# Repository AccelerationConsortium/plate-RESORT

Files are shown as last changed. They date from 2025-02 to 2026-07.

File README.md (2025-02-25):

## About the Project
Plate hotels and carousels are **space-efficient storage systems** designed for well plates, making them ideal for **high-throughput automated workflows** in chemistry and biology labs. This project provides **open-source, low-cost instructions** for building modular storage solutions tailored to your lab's needs.

- **Plate Hotel**: The base design accommodates **11 well plates**, but it can be easily customized to be taller or shorter depending on your requirements.
- **Plate Carousel**: Built around a **Raspberry Pi Zero 2 W**, this system features an **automated turntable base** and can hold **6 plate hotels** (totaling **60 well plates**), enabling efficient access and organization.

TODO: add pictures

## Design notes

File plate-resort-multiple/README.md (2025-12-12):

# Plate Resort - Quick Setup Guide

Control laboratory plate handling hardware from your computer.

## Setup Steps

### 1. Get the API Key
SSH into the Pi and get the key:
```bash
ssh your_username@pi_ip_address
cd ~/plate-RESORT/plate-resort-multiple
plate-resort-rest-server
```
Copy the API key shown, then press `Ctrl+C`.

### 2. Install on Your Computer
```bash
git clone https://github.com/AccelerationConsortium/plate-RESORT.git
cd plate-RESORT/plate-resort-multiple
pip install -e .
```

### 3. Set Connection Info
**Windows:**
```cmd
set PLATE_RESORT_API_KEY=your-api-key-here
set PLATE_RESORT_URL=http://sdl3-pi5-plate-resort.tail6a1dd7.ts.net:8000
```

**Mac/Linux:**
```bash
export PLATE_RESORT_API_KEY="your-api-key-here"
export PLATE_RESORT_URL="http://sdl3-pi5-plate-resort.tail6a1dd7.ts.net:8000"
```

### 4. Start the Pi Server
SSH back to Pi:
```bash
plate-resort-rest-server
```
Keep this running.

## Commands

**Check status:**
```bash
plate-resort-rest-client status
```

**Move to hotel:**
```bash
plate-resort-rest-client activate A  # or B, C, D
```

**Go home:**
```bash
plate-resort-rest-client home
```

**Emergency stop:**
```bash
plate-resort-rest-client stop
```

## Troubleshooting

- **Connection refused:** Check Pi server is running and IP address is correct
- **Authentication failed:** Double-check your API key  
- **Motor issues:** SSH to Pi and run `python tests/soft_reset.py`

## For GUI Development

All commands return JSON responses. Use any programming language to build your interface:
- Python (tkinter, PyQt, Streamlit)
- Web (HTML/JavaScript) 
- LabVIEW, MATLAB, etc.

Choose your interface mode based on your needs. Both modes can run on the same Raspberry Pi if needed.

## 2A. Prefect Interface Setup (Recommended)

### 2A.1 Raspberry Pi (Worker Host)
```bash
export PREFECT_API_URL="https://api.prefect.cloud/api/accounts/<account-id>/workspaces/<workspace-id>"
export PREFECT_API_KEY="pnu_XXXXXXXXXXXXXXXX"

python3 -m venv plate-resort-env
source plate-resort-env/bin/activate
pip install -e .
plate-resort-prefect-deploy     # registers deployments
plate-resort-prefect-worker    # starts Prefect worker
```
Optional systemd (adjust path/username):
```bash
sudo cp deployment/plate-resort.service /etc/systemd/system/
sudo systemctl daemon-reload
sudo systemctl enable --now plate-resort.service
```
Environment file (example): `/home/<user>/plate-RESORT/secrets.local.env`
```
PREFECT_API_URL=...
PREFECT_API_KEY=...
PLATE_RESORT_POOL=plate-resort-pool
```

### 2A.2 Client Machine
Two supported approaches:
1. Interactive CLI (`plate-resort-prefect-interactive --remote`)
2. Minimal script (`plate_resort/client/example_prefect_client.py` pattern)

Install only what’s needed:
```bash
python -m venv plate-resort-client
source plate-resort-client/bin/activate
pip install -r client-requirements.txt
```
Export credentials (or source `plate_resort/client/env.sh` after editing IDs):
```bash
source plate_resort/client/env.sh   # edit placeholders first
```
Verify a deployment submission:
```bash
python -c "from plate_resort.interfaces.prefect import orchestrator; print(orchestrator.connect())"
```

## 2B. REST API Interface Setup (Traditional)

### 2B.1 Raspberry Pi (Server Host)
```bash
python3 -m venv plate-resort-env
source plate-resort-env/bin/activate
pip install -e .
plate-resort-keygen                 # generate API key
plate-resort-rest-server           # start FastAPI server
```
The server runs on port 8000 by default. API documentation available at `http://<pi-ip>:8000/docs`

### 2B.2 Client Machine  
```bash
python -m venv plate-resort-client
source plate-resort-client/bin/activate
pip install -e .
export PLATE_RESORT_BASE_URL="http://<pi-ip>:8000"
export PLATE_RESORT_API_KEY="<generated-key>"
plate-resort-rest-client --help    # see available commands
```

Example REST usage:
```bash
# Connect and activate hotel
plate-resort-rest-client connect
plate-resort-rest-client activate A
plate-resort-rest-client position
plate-resort-rest-client disconnect
```

## 3. Client Usage (Prefect Interface)

### 3.1 Interactive CLI
```bash
plate-resort-prefect-interactive --remote
```
Commands:
```
connect | activate <A|B|C|D> | position | stop | disconnect | help | exit
```

### 3.2 Example Script (A -> D)
```bash
python plate_resort/client/example_prefect_client.py
```
That script: activates hotel A, waits, then activates hotel D with state checks.

### 3.3 Direct Orchestrator Calls
```python
from plate_resort.interfaces.prefect import orchestrator
run = orchestrator.activate_hotel("A")
state = orchestrator.wait(run)
print(state.type)
```

## 4. Deployments & Redeploy (Prefect Interface)
Run on Pi whenever code changes:
```bash
plate-resort-prefect-deploy
```
This re-registers function-based flows with Prefect Cloud using the current working tree (Git storage reference if configured).

Pinning / ensuring correct source:

Option A (branch ref):
```bash
export PLATE_RESORT_GIT_REF=copilot/replace-rest-api-with-prefect
plate-resort-prefect-deploy
```
Option B (commit hash, reproducible) – recommended; resolved prior path issues during testing:
```bash
export PLATE_RESORT_GIT_COMMIT=$(git rev-parse HEAD)
plate-resort-prefect-deploy
```
Commit pin (Option B) takes precedence over branch ref and guarantees the worker loads the exact code you just validated.

## 5. Available Flows
All in `plate_resort/interfaces/prefect/flows.py`:
```
connect, disconnect, activate_hotel, move_to_angle,
get_current_position, get_motor_health, go_home,
emergency_stop, set_speed
```
Remote submission uses deployment names of form `flow-name/flow-name` (e.g. `activate-hotel/activate-hotel`).

## 6. Behavior Notes
* Motor connection is re-established per flow if needed and left active afterward (persistent torque).
* Use `disconnect` flow to deliberately release torque/close port.
* `orchestrator.wait()` polls Prefect for a final state.

## 7. Configuration
Search path includes packaged defaults plus optional override directory: `~/plate-resort-config/`.

`defaults.yaml` (excerpt):
```yaml
resort:
  device: "/dev/ttyUSB0"
  hotels: ["A", "B", "C", "D"]
prefect:
  work_pool_name: "plate-resort-pool"  # Overridden by PLATE_RESORT_POOL
```

To override: create `~/plate-resort-config/defaults.yaml` with keys you want to change; unspecified values fall back to packaged defaults.

## 8. Minimal Client Assets
* `client-requirements.txt` – pins `prefect` + `pyyaml` (add `dynamixel-sdk` only if talking directly to hardware from client).
* `plate_resort/client/env.sh` – template for exporting Prefect API variables.
* `plate_resort/client/example_prefect_client.py` – sequential A -> D example.

## 9. Troubleshooting
| Symptom | Likely Cause | Fix |
|---|---|-----|
| Flow run stays SCHEDULED | Worker not running or wrong pool | Start worker; confirm pool name or set PLATE_RESORT_POOL |

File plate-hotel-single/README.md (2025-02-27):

# Plate Hotel Build Guide
This document provides the steps required to assemble the plate hotel. Please review all instructions and notes before starting the build.

## Bill of Materials
### Purchased Parts

| # | McMaster Part # | Part Description | Quantity |
|-----|---|---|---|
| A1  | 92125A234 | M6 FH screw, 10mm L, SS | 22 |
| A2  | 93590A106 | M6 Coupling Nut, 18mm L, SS | 22 |
| A3  | 94639A569 | M6 Spacer, 1/4in L, Nylon | 3 |
| A4  | 92095A224 | M6 PH Screw, 10mm L, SS | 22 |
| A5  | 8961K96 | DIN 3 Rail, 600mm L, S | 1 |
| A6  | 4844N123 | single closed gusset for 25mm rail (with fasteners) | 3 |
| A7  | 92095A128 | M6 PH Screw, 15mm L, SS | 3 |
| A8  | 4633N79 | extrusion, square, 25mm, 2ft L | 1 |
| A9  | 94180A371 | M6 heat set insert | 3 |
| A10 | 3136N534 | cap, 25mm rail | 1 |
| A11 | 91458A115 | threadlocker, Loctite 243 (medium) | N/A |

<sub>Note: I like stainless steel screws, this is not necessary. The lengths are listed in the part description.</sub>
---

### 3D Printed Parts

| # | Filament Qty (g) | Part Name | Part Qty |
|-----|---|---|---|
| B1  | 48.9 | well plate tray | 11 |
| B2  | 50 | plate hotel base  | 1 |

<sub>Note: The well plate trays are intended to print in vertical orientation. See *4xB1 well_plate_trays.3mf* file.</sub>
---

## Tools Required

- **Soldering iron/heat set tool**
- **Allen keys**

---

## Assembly Notes

- **BOM References:**  
  Numbers in square brackets indicate the required quantities and the corresponding part numbers from the Bill of Materials (BOM).

- **Build Configuration:**  
  This build is designed for a 2ft long rail accommodating 11 well plate slots spaced 50mm apart. Adjust the lengths, spacing, and quantities for custom configurations if needed.

- **Base Plate:**  
  The base plate is intended to be screwed into a breadboard with M6 threads and 25mm spacing.

---

## Assembly Instructions

1. **Install Heat Set Inserts:**  
   - Insert 3 heat set inserts [3x A9] into the plate hotel base [1x B2].
<p align="center">
  
</p>

2. **Attach Coupling Nuts to the DIN Rail:**  
   - Secure 22 coupling nuts [22x A2] to the DIN rail using 22 M6x10mm L pan head screws [22x A4] and threadlocker [A11].  The DIN rail has 24 slots, leave the first and last slot empty (the 
   - **Note:** Ensure the screws and nuts are aligned on the right side of the DIN rail slot (the image provided shows the right side as the bottom of the rail).
<p align="center">
  
</p>

3. **Prepare Components for Attaching the DIN Rail:**  
   Gather the following parts:
   - 3 M6 15mm L screws [3x A7]
   - 3 M6 spacers [3x A3]
   - 3 track nuts (from the gusset associated with part A6; use 3 out of the 6 provided)

4. **Assemble the DIN Rail to the Extrusion:**  
   - Fasten the DIN rail to the square extrusion rail by placing the screws, spacers, and track nuts at approximately the top, middle, and bottom positions.  
   - **Tip:** Align one edge of the rail with the extrusion; this aligned edge will serve as the bottom that contacts the base.  This can be done this after step 5 once the base is assembled.

<p align="center">
  
</p>
<p align="center">
  
</p>

5. **Attach the Rail/Extrusion Assembly to the Hotel Base:**  
   - Use gussets [3x A6] (screws and nuts included with gusset) to secure the assembly.
     - Fasten a nut along three of the extrusion tracks to attach the gusset to the extrusion.
     - Thread the remaining screw into the heat set insert [A9] to secure the gusset to the base.
   - **Ensure:** The edge of the DIN rail touches the base after installation.

<p align="center">
  
</p>

6. **Install the Well Plate Trays:**  
   - Insert the 10 well plate trays [11x B1] into the coupling nuts along the rail.
   - Each tray is secured by 2 M6x10mm L flat head screws [22x A1].
<p align="center">
  
</p>

7. **Final Step – Cap Cover Installation:**  
   - Press the cap cover [1x A10] onto the top of the extrusion.
  
<p align="center">
  
</p>

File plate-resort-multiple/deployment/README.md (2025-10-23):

# Deployment: persistent worker systemd unit

This folder contains a sample systemd unit to run the repository's persistent Prefect worker (the custom Python worker implemented at `plate_resort.workflows.worker_service`) on a Raspberry Pi.

Key points
- The unit expects an EnvironmentFile at `/home/ac/plate-RESORT/secrets.local.env` containing at least:
  - PREFECT_API_URL=...
  - PREFECT_API_KEY=...
  - PREFECT_CLI_PROMPT=false
- A Python virtualenv is expected at `/home/ac/plate-RESORT/plate-resort-env`. Adjust paths if your venv lives elsewhere.

Install steps (run on the Pi as a user with sudo):

1) Copy the unit file to systemd

```bash
sudo cp /home/ac/plate-RESORT/deployment/plate-resort.service /etc/systemd/system/plate-resort.service
sudo chown root:root /etc/systemd/system/plate-resort.service
sudo chmod 644 /etc/systemd/system/plate-resort.service
```

2) Ensure your secrets file exists and is correct (example)

```bash
cat > /home/ac/plate-RESORT/secrets.local.env <<EOF
PREFECT_API_URL=https://api.prefect.cloud/api/accounts/<ACCOUNT>/workspaces/<WORKSPACE>
PREFECT_API_KEY=<YOUR_API_KEY>
PREFECT_CLI_PROMPT=false
EOF
sudo chown ac:ac /home/ac/plate-RESORT/secrets.local.env
chmod 600 /home/ac/plate-RESORT/secrets.local.env
```

3) Reload systemd and start the service

```bash
sudo systemctl daemon-reload
sudo systemctl enable --now plate-resort.service
```

4) Watch logs

```bash
sudo journalctl -u plate-resort.service -f
```

5) If it still exits with prompts or errors, run the ExecStart command manually while the venv is activated to reproduce

```bash
su - ac
source /home/ac/plate-RESORT/plate-resort-env/bin/activate
python -m plate_resort.workflows.worker_service
```

If you want the unit to run the Prefect CLI worker instead, edit `ExecStart` to include your desired pool name or use the environment variable `PLATE_RESORT_POOL` in your EnvironmentFile. Example using an explicit pool name:

```text
ExecStart=/bin/bash -lc 'source /home/ac/plate-RESORT/plate-resort-env/bin/activate && exec prefect worker start --pool "plate-resort-pool" --type process --install-policy if-not-present'
```

Or set `PLATE_RESORT_POOL` in `/home/ac/plate-RESORT/secrets.local.env` and use the custom Python worker (recommended) which will pick it up automatically.

Note: the custom Python worker is recommended for hardware persistence because it maintains a single PlateResort instance across runs.

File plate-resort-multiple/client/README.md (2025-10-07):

# Server-Client API Examples

## Quick Examples

### Start the server:
```bash
cd ~/plate-resort/plate-resort-multiple
source venv/bin/activate
./server/run_server.sh
```

### Use the Python client:
```bash
# Connect to motor
python client/client.py connect

# Check status
python client/client.py status

# Move to hotel A
python client/client.py activate A

# Get motor health
python client/client.py health

# Emergency stop
python client/client.py stop
```

### Use curl directly:
```bash
# Set API key
API_KEY="changeme"
API_URL="http://your-pi-ip:8000"

# Connect
curl -X POST "$API_URL/connect" \
  -H "x-api-key: $API_KEY" \
  -H "Content-Type: application/json" \
  -d '{"device": "/dev/ttyUSB0", "baudrate": 57600, "motor_id": 1}'

# Activate hotel A
curl -X POST "$API_URL/activate" \
  -H "x-api-key: $API_KEY" \
  -H "Content-Type: application/json" \
  -d '{"hotel": "A"}'

# Get status
curl -X GET "$API_URL/status" -H "x-api-key: $API_KEY"
```

## Configuration

Set environment variables:
```bash
export PLATE_API_KEY="your-secret-key"
export PLATE_API_URL="http://your-pi-ip:8000"
```

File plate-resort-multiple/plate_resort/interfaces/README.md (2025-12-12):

# PlateResort Interfaces

This directory contains the two main interface modes for the PlateResort system:

## Architecture Overview

```
plate_resort/
├── core.py                 # Shared motor control functionality
├── config/                 # Configuration system
├── utils/                  # Shared utilities
├── client/                 # Client-side tools
└── interfaces/             # Interface implementations
    ├── prefect/           # Modern workflow orchestration
    │   ├── flows.py       # Prefect flow definitions
    │   ├── orchestrator.py # Flow orchestration logic
    │   ├── deploy.py      # Deployment management
    │   └── worker_service.py # Prefect worker service
    └── rest_api/          # Traditional HTTP API
        ├── main.py        # FastAPI application
        └── wrapper.py     # REST endpoint wrapper
```

## Interface Modes

### Prefect Interface (`interfaces/prefect/`)
Modern cloud-native workflow orchestration using Prefect v3.

**Features:**
- Cloud-native workflow management
- Robust error handling and retries
- Remote deployment and monitoring
- Scalable task distribution
- Real-time logging and observability

**Console Scripts:**
- `plate-resort-prefect-interactive` - Interactive flow execution
- `plate-resort-prefect-worker` - Start Prefect worker service
- `plate-resort-prefect-deploy` - Deploy workflows to Prefect cloud

### REST API Interface (`interfaces/rest_api/`)
Traditional HTTP-based API server using FastAPI.

**Features:**
- Synchronous HTTP endpoints
- Direct motor control
- Simple request/response pattern
- API key authentication
- OpenAPI documentation

**Console Scripts:**
- `plate-resort-rest-server` - Start FastAPI server
- `plate-resort-rest-client` - Command-line REST client

## Choosing an Interface

**Use Prefect when:**
- Building complex automated workflows
- Need cloud connectivity and monitoring
- Require robust error handling and retries
- Working in production environments
- Need to coordinate multiple operations

**Use REST API when:**
- Building simple integrations
- Need direct synchronous control
- Prefer traditional HTTP patterns
- Working with existing REST-based systems
- Need immediate response feedback

Both interfaces share the same underlying `PlateResort` core functionality and configuration system.

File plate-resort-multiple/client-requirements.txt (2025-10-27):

# Minimal client requirements for submitting Prefect Plate Resort deployments.
# Remote-only (no hardware): prefect + pyyaml
# Local hardware: add dynamixel-sdk

prefect==3.4.23
pyyaml>=6.0
# dynamixel-sdk>=3.8.4  # optional for hardware access

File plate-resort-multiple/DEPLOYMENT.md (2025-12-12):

# Deployment Notes

## Quick Pi Setup

1. **Clone and Install:**
   ```bash
   git clone https://github.com/AccelerationConsortium/plate-RESORT.git
   cd plate-RESORT/plate-resort-multiple
   python3 -m venv plate-resort-env
   source plate-resort-env/bin/activate
   pip install -e .
   ```

2. **Generate API Key:**
   ```bash
   plate-resort-keygen --generate --update-config --create-env
   export PLATE_API_KEY=$(grep PLATE_API_KEY .env | cut -d'=' -f2)
   ```

3. **Start Services:**
   ```bash
   # REST API Server
   plate-resort-rest-server
   
   # OR Prefect Worker
   plate-resort-prefect-worker
   ```

4. **REST API Client Usage:**
   ```bash
   # Available commands: connect, disconnect, status, position, activate
   plate-resort-rest-client connect
   plate-resort-rest-client status
   plate-resort-rest-client position
   plate-resort-rest-client activate A
   plate-resort-rest-client disconnect
   ```

## Auto-activation Setup
```bash
echo "cd ~/plate-RESORT/plate-resort-multiple && source plate-resort-env/bin/activate" >> ~/.bashrc
```

## Fixed Issues
- ✅ File corruption in cli_rest.py and keygen_rest.py 
- ✅ API key configuration for REST server
- ✅ Environment variable precedence in wrapper.py
- ✅ Console script naming and paths
- ✅ Dual interface architecture (REST + Prefect)

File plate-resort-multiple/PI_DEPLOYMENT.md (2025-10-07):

# Plate Resort - Pi Deployment Guide

## 🚀 Optimized Web GUI for 7" Touchscreen

This version provides a modern, responsive web interface specifically optimized for the Raspberry Pi 7" touchscreen (800x480 resolution).

### ✨ Key Features:

- **Perfect 7" Display Fit**: Designed specifically for 800x480 resolution
- **Touch-Optimized**: Large, responsive buttons for finger navigation
- **No Scrolling Required**: All controls visible without scrolling
- **Modern Bootstrap Design**: Professional, clean interface
- **Real-time Updates**: Live motor health monitoring
- **Network Accessible**: Control from any device on the network
- **Hardware Integration**: Works with real Dynamixel motors

### 🛠️ Quick Setup on Raspberry Pi:

1. **Clone the repository**:
   ```bash
   cd /home/pi
   git clone <your-repo-url> plate-resort
   cd plate-resort
   ```

2. **Start the web GUI**:
   ```bash
   chmod +x start-web-gui.sh
   ./start-web-gui.sh
   ```

3. **Open in fullscreen browser**:
   - Launch Chromium: `chromium-browser --start-fullscreen http://localhost:5000`
   - Or click the desktop shortcut (if installed)

### 📱 Interface Layout:

#### Control Tab:
- **8 Hotel Buttons**: Compact grid layout, all visible
- **System Controls**: Home and Emergency Stop
- **Position Display**: Current motor angle

#### Status Tab:
- **Motor Health**: Temperature, Voltage, Current, Load
- **Real-time Monitoring**: Live updates every 5 seconds

#### Debug Tab:
- **Terminal Console**: Green-on-black debug output
- **Live Monitoring**: Toggle real-time diagnostics
- **Compact Design**: Fits in 200px height

### 🎯 Optimizations for 7" Display:

- **Button Height**: 45px for hotel buttons, 40px for controls
- **Compact Spacing**: 4px gaps between elements
- **Readable Fonts**: 0.9em base size, Segoe UI family
- **Touch Targets**: Minimum 40px touch areas
- **Scrollable Content**: Tab content scrolls if needed
- **Responsive Grid**: 4x2 hotel button layout

### 🌐 Network Access:

The interface is accessible from any device on your network:
- **Pi Direct**: http://localhost:5000
- **Network**: http://[pi-ip]:5000
- **Mobile/Tablet**: Full responsive design

### 🔧 System Deployment:

The system runs directly with Python for simplicity:

```bash
# Start optimized web GUI
./start-web-gui.sh

# Or manually:
pip3 install -r requirements.txt
python3 web_gui.py

# Stop system
pkill -f web_gui.py
```

### 📋 File Structure:

```
plate-resort/
├── web_gui.py              # Flask app for web interface
├── templates/
│   └── web_gui.html        # Touchscreen optimized interface
├── start-web-gui.sh        # Simple launcher script
├── start-web-gui.sh        # Web GUI launcher
├── test_scripts/
│   └── test_pi_gui.py      # Local testing script
└── plate-resort-pi.desktop # Desktop shortcut
```

### 🎨 Design Philosophy:

- **Minimal but Functional**: No wasted space
- **Touch-First**: Designed for finger interaction
- **Professional**: Clean, laboratory-appropriate styling
- **Efficient**: Fast loading, smooth animations
- **Reliable**: Robust error handling and status feedback

### 🔄 Upgrading from Old GUI:

The new web interface replaces the tkinter GUI with significant improvements:

| Old tkinter GUI | New Web GUI |
|---|---|
| Basic styling | Modern Bootstrap design |
| Fixed window | Responsive, fullscreen |
| Limited touch support | Touch-optimized |
| Desktop only | Network accessible |
| Scrolling issues | Perfect fit for 7" screen |
| System dependencies | Python requirements.txt |

### 🚀 Auto-Start Setup:

1. **Install desktop file**:
   ```bash
   cp plate-resort-pi.desktop ~/.local/share/applications/
   chmod +x ~/.local/share/applications/plate-resort-pi.desktop
   ```

2. **Auto-launch on boot** (optional):
   ```bash
   # Add to ~/.config/lxsession/LXDE-pi/autostart
   echo "@/home/pi/plate-resort/start-pi-gui.sh" >> ~/.config/lxsession/LXDE-pi/autostart
   ```

### 🔍 Troubleshooting:

- **GUI not loading**: Check terminal output or `ps aux | grep web_gui`
- **Hardware issues**: Verify USB device permissions and connections
- **Network access**: Ensure port 5000 is not blocked
- **Touch problems**: Verify touchscreen calibration

### 🎯 Performance:

- **Startup Time**: ~2-3 seconds direct Python
- **Response Time**: <200ms for button presses
- **Memory Usage**: ~50MB container footprint
- **CPU Usage**: <5% on Pi 4

This optimized interface provides a professional, touch-friendly control system that perfectly fits the 7" touchscreen while maintaining all the functionality of the original system.

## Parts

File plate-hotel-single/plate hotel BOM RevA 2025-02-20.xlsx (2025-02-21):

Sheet: plate hotel BOM
Plate Hotel BOM
Purchased Parts
# | Mcmaster Part # | Part Name | Quantity | Unit Cost (USD) | Unit Cost (CAD) | Total Cost (CAD)
A1 | 92125A234 | M6 FH screw, 10mm L, SS | 20 | $0.20 | $0.29 | $5.76
A2 | 93590A106 | M6 Coupling Numt 18mm L, SS | 20 | $0.89 | $1.28 | $25.63
A3 | 94639A569 | M6 Spacer, 1/4in L, Nylon | 3 | $0.18 | $0.26 | $0.77
A4 | 92095A224 | M6 PH Screw, 10mm L, SS | 20 | $0.23 | $0.33 | $6.68
A5 | 8961K96 | DIN 3 Rail, 600mm L, S | 1 | $5.70 | $8.21 | $8.21
A6 | 4844N111 | single closed gusset for 25mm rail (with fasteners) | 3 | $5.90 | $8.50 | $25.49
A7 | 92095A128 | M6 PH Screw, 15mm L, SS | 3 | $0.23 | $0.33 | $0.98
A8 | 4633N79 | extrusion, square, 25mm, 2ft L | 1 | $10.62 | $15.29 | $15.29
A9 | 92125A111 | M6 FH screw, 15mm L, SS | 1 | $0.19 | $0.27 | $0.27
A10 | 94180A371 | M6 heat set insert | 3 | $0.55 | $0.79 | $2.38
A11 | 3136N534 | cap, 25mm rail | 1 | $2.65 | $3.82 | $3.82
A12 | 91458A115 | threadlocker, Loctite 243 (medium) | N/A | $0.00 | $0.00 | $0.00
3D Printed Parts
# | Filament qty (g) | Filament Qty (g) | Part Qty | Filament Cost (per kg) | Unit Cost (CAD) | Total Cost (CAD)
B1 | 48.9 | well plate tray | 10 | $19.99 | $0.98 | $9.77
B2 | 50 | plate hotel base | 1 | $19.99 | $1.00 | $1.00
 |  |  |  |  | SUM | $106.06

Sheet: revision history
Revision | Change Description | Date
A | Initial Release | 2025-02-20

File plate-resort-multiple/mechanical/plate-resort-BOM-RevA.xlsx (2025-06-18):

Mcmaster Carr Purchased Parts
# | Mcmaster Part # | Part Name | Quantity | Unit Cost (USD) | Unit Cost (CAD) | Total Cost (CAD)
A1 | 92125A104 | M4 FH screw, 15mm L | 8 | 0.0928 | $0.13 | $1.02
A2 | 98952a029 | M4 standoff, M-F, 12mm L | 4 | 0.92 | $1.26 | $5.04
A3 | 95947a071 | M4 standoff long, F-F, 40mm | 8 | 1.49 | $2.04 | $16.33
A4 | 92125A190 | M4 FH screw, 10mm L | 8 | 0.095 | $0.13 | $1.04
A5 | 92125a202 | M4 FH screw, 25mm | 4 | 0.192 | $0.26 | $1.05
A6 | 4844N111 | single closed gusset for 25mm rail (with fasteners) | 4 | $5.90 | $8.08 | $32.33
A7 | 8961k15 | din rail, 1m | 4 | 7.06 | $9.67 | $38.69
A8 | 4633n81 | 3ft extrusion | 1 | 14.67 | $20.10 | $20.10
A9 | 93590A106 | M6 Coupling Numt 18mm L, SS | 160 | $0.47 | $0.64 | $103.02
A10 | 94639A569 | M6 Spacer, 1/4in L, Nylon | 16 | $0.18 | $0.25 | $3.92
A11 | 92095A128 | M6 PH Screw, 15mm L, SS | 16 | $0.23 | $0.31 | $5.00
A12 | 92125A234 | M6 FH screw, 10mm L, SS | 160 | $0.20 | $0.27 | $43.84
A13 | 92095A224 | M6 PH Screw, 10mm L, SS | 160 | $0.23 | $0.32 | $50.81
A14 | 91406a102 | m6-m8 thread adapter | 1 | $6.73 | $9.22 | $9.22
A15 | 9129a480 | m8 screw | 1 | 1.656 | $2.27 | $2.27
A16 | 91458A115 | threadlocker, Loctite 243 (medium) | N/A | $0.00 | $0.00 | $0.00
A17 | 94180A371 | M6 heat set insert | 20 | $0.55 | $0.76 | $15.12
 |  | bearing
Other Purchased Pats
# | Part # | Part Name | Vendor | Quantity | Unit Cost | Currency | Total Cost
 |  | Servo Motor | Robotshop | 1 | 34.56 | CAD | $34.56
 |  | servo hub short | Robotshop | 1 | 14.69 | CAD | $14.69
 |  | bearing | igus | 4 | 6.97 | USD | $9.55
 |  | pi zero 2w | pishop |  | 21.5 | CAD | $21.50
 |  | tft bonnet | digikey |  | 28.3 | CAD | $28.30
 |  | grove adc | digikey |  | 12.7 | CAD | $12.70
 |  | misc | digikey |  | 50 | CAD | $50.00
3D Printed Parts
# | Filament qty (g) | Filament Qty (g) | Part Qty | Filament Cost (per kg) | Unit Cost (CAD) | Total Cost (CAD) |  | total filament | total time
76.66666667 | 48.9 | well plate tray | 80 | $19.99 | $0.98 | $78.16 |  | 3910 | 6133.333333
258 | 311 | bottom housing-rotating | 1 | $19.99 | $6.22 | $6.22 | 100%infill | 311 | 258
282 | 297 | bottom housing-base | 1 | $19.99 | $5.94 | $5.94 | 100%infill | 297 | 282
261 | 272 | bottom housing-bottom | 1 | $19.99 | $5.44 | $5.44 | 100%infill | 272 | 261
78 | 47.6 | rail adapter | 4 | $19.99 | $0.95 | $3.81 | .16 optimal | 190.4 | 312
55 | 42.5 | regrip plates | 2 | $19.99 | $0.85 | $1.70 | .16 optimal | 85 | 110
196 | 134 | top bearing | 1 | $19.99 | $2.68 | $2.68 | .2 strenght | 134 | 196
 |  |  |  |  |  |  |  |  | 125.8666667

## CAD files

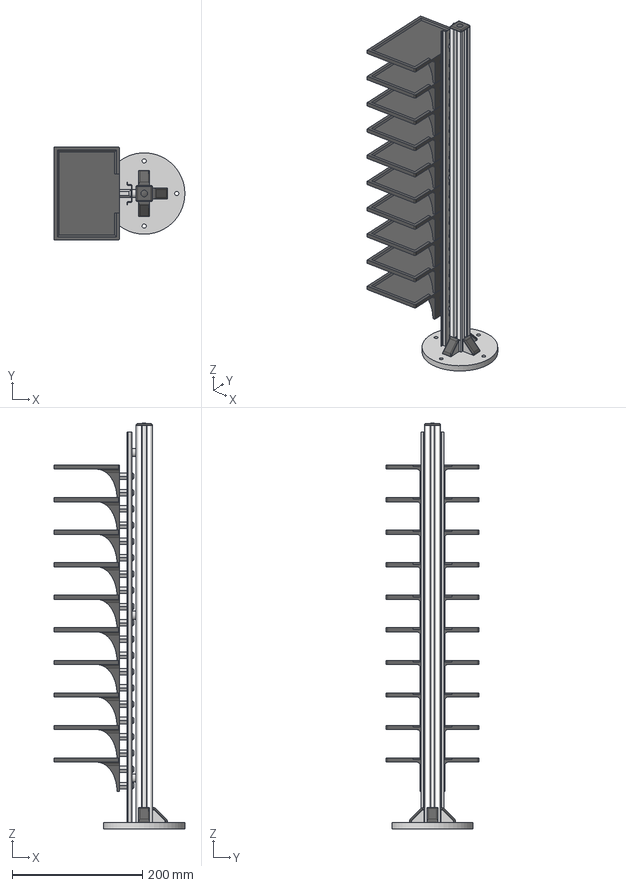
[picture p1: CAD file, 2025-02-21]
plate-hotel-single/3D printed parts/assembly reference/assembly_plate_hotel RevA.step
200.8 x 143.0 x 623.6 mm
4633N79_T-Slotted Framing Rail
plate_hotel_base
8961K96_Steel DIN 3 Rail
93590A106_NO THREADS_18-8 Stainless Steel Coupling Nut x 20
well_plate_tray x 10
92095A224_NO THREADS_Button Head Hex Drive Screw x 20
94639A569_Off-White Nylon Unthreaded Spacer x 3
92095A128_NO THREADS_Button Head Hex Drive Screw x 3
92125A234_NO THREADS_18-8 Stainless Steel Hex Drive Flat Head Screw x 20
92125A111_NO THREADS_18-8 Stainless Steel Hex Drive Flat Head Screw
94180A371_NO THREADS_Tapered Heat-Set Inserts for Plastic x 3
4844N111_NO THREADS_T-Slotted Framing Structural Bracket x 3
3136N534_T-Slotted Framing

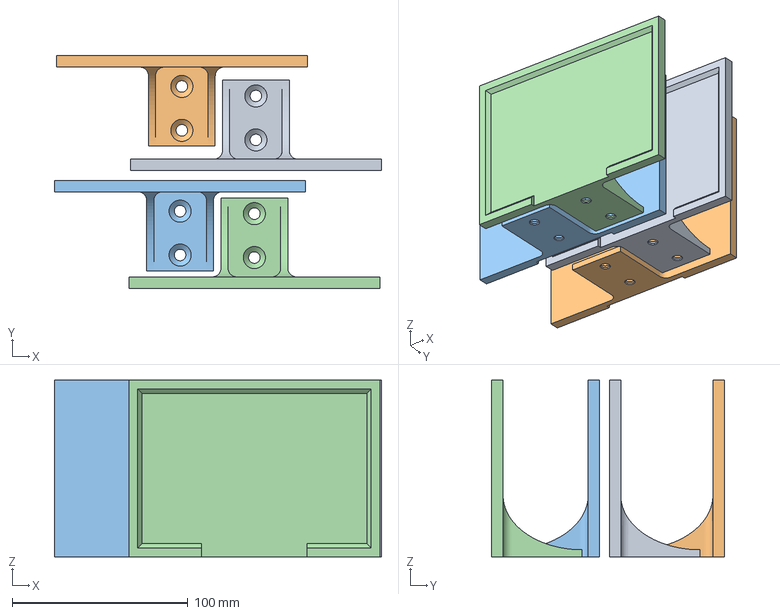
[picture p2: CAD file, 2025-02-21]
plate-hotel-single/3D printed parts/4xB1 well_plate_trays.3mf
186.1 x 132.4 x 100.5 mm
well plate tray-merged v9.stl x 4

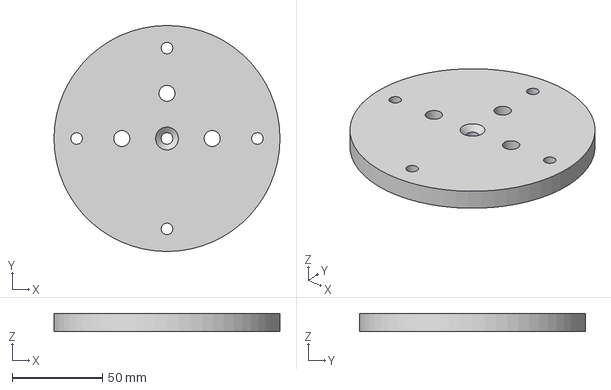
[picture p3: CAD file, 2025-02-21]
plate-hotel-single/3D printed parts/B2 plate_hotel_base RevA.step
125.0 x 125.0 x 10.0 mm

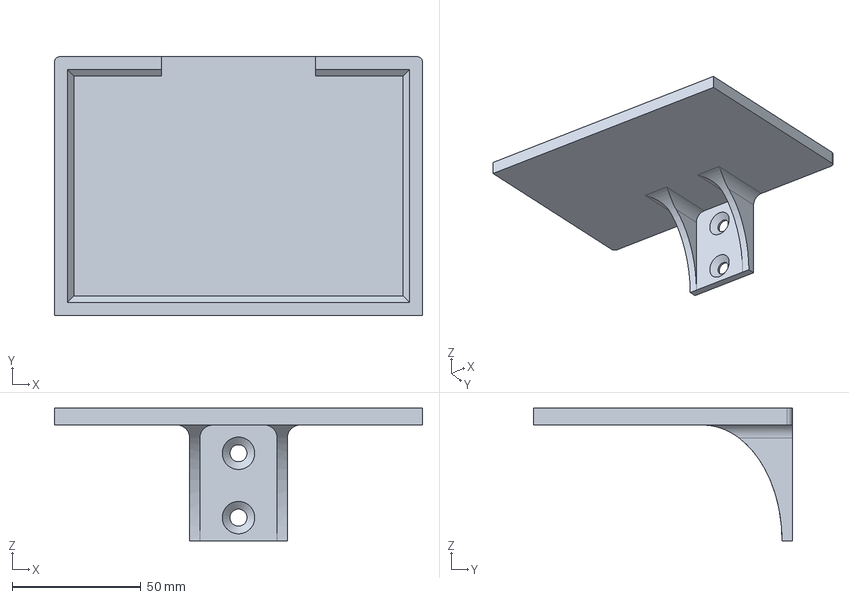
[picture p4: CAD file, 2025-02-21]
plate-hotel-single/3D printed parts/B1 well_plate_tray RevA.step
143.0 x 100.5 x 51.5 mm

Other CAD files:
plate-hotel-single/3D printed parts/B1 well_plate_tray RevA.stl
plate-hotel-single/3D printed parts/B2 plate_hotel_base RevA.stl
plate-hotel-single/3D printed parts/assembly reference/assembly_plate_hotel RevA.f3z

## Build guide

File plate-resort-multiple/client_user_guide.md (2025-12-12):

# Plate Resort REST API Client User Guide

This guide shows you how to control the Plate Resort from your computer using the REST API. The Raspberry Pi hardware is already set up - you just need to install the client software.

## Step 1: Get the API Key from the Pi

SSH into the Raspberry Pi to get your access key:

```bash
ssh your_username@pi_ip_address
cd ~/plate-RESORT/plate-resort-multiple
```

Check if the server is running:
```bash
plate-resort-rest-server
```

You'll see something like:
```
🔑 API Key: Xp9mK3vR8qL2nBw7cF4jY1eH6sD0zM5t
```

**Copy this key** - you'll need it later. Press `Ctrl+C` to stop.

## Step 2: Install Client Software

On your computer, install the software:

```bash
git clone https://github.com/AccelerationConsortium/plate-RESORT.git
cd plate-RESORT/plate-resort-multiple
pip install -e .
```

## Step 3: Configure Your Connection

Set your connection details:

**Windows:**
```cmd
set PLATE_RESORT_API_KEY=Xp9mK3vR8qL2nBw7cF4jY1eH6sD0zM5t
set PLATE_RESORT_URL=http://sdl3-pi5-plate-resort.tail6a1dd7.ts.net:8000
```

**Mac/Linux:**
```bash
export PLATE_RESORT_API_KEY="Xp9mK3vR8qL2nBw7cF4jY1eH6sD0zM5t"
export PLATE_RESORT_URL="http://sdl3-pi5-plate-resort:8000"
```

Replace the hostname with your Pi's actual hostname or IP address.

## Step 4: Start the Pi Server

SSH back to the Pi and start the server:
```bash
plate-resort-rest-server
```
Leave this running while you use the system.

## Control Commands

Now you can control the Plate Resort from your computer:

| Command | Purpose | Example |
|---|---|---|
| `connect` | Connect to the motor | `plate-resort-rest-client connect` |
| `status` | Check if everything is working | `plate-resort-rest-client status` |
| `position` | Get current position | `plate-resort-rest-client position` |
| `activate` | Move to hotel A, B, C, or D | `plate-resort-rest-client activate A` |
| `move` | Move to specific angle | `plate-resort-rest-client move 90.0` |
| `home` | Return to home position | `plate-resort-rest-client home` |
| `stop` | Emergency stop | `plate-resort-rest-client stop` |
| `health` | Check motor health | `plate-resort-rest-client health` |
| `disconnect` | Disconnect from motor | `plate-resort-rest-client disconnect` |

## Troubleshooting

**401 Authentication Error:** Check your API key is correct and matches exactly

**500 Server Error:** Hardware fault detected - SSH to Pi and run `python tests/soft_reset.py`

**Can't connect:** Check that Pi and client are both on the same network and online

**Motor configuration adjustments:** Edit `plate_resort/config/defaults.yaml` file on the Pi for motor control settings

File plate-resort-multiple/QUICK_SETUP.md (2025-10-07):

# Plate Resort Server - Quick Setup

A streamlined Plate Resort control system for Raspberry Pi with one-line installation.

## One-Line Installation

On a fresh Raspberry Pi with Raspberry Pi OS, run:

```bash
curl -fsSL https://raw.githubusercontent.com/AccelerationConsortium/plate-RESORT/main/plate-resort-multiple/install.sh | bash
```

This will:
- Clone the repository to `~/plate-resort`
- Install all required system dependencies
- Set up Python packages (dynamixel-sdk, pyyaml)
- Configure USB permissions for Dynamixel motors
- Create a simple runner script

## Quick Start

After installation and reboot:

## Local Usage
```bash
cd ~/plate-resort/plate-resort-multiple
./run_server.sh
```

Or manually activate the environment:

```bash
cd ~/plate-resort/plate-resort-multiple
source venv/bin/activate
python plate_resort.py
```

## Server Mode (Remote Access)
```bash
cd ~/plate-resort/plate-resort-multiple
source venv/bin/activate
./server/run_server.sh
```

Access from any device on the network:
- API: `http://your-pi-ip:8000`
- Documentation: `http://your-pi-ip:8000/docs`

## Core Components

- `plate_resort.py` - Main motor control class
- `resort_config.yaml` - Configuration file
- `test_scripts/` - Motor testing utilities
- `requirements.txt` - Python dependencies (minimal)

## Basic Usage

### Local Control
```bash
source venv/bin/activate
python test_scripts/test_dxl_ping.py --device /dev/ttyUSB0 --id 1
python example_usage.py
```

### Remote Control (Client)
```bash
# From any machine on the network
python client/client.py connect
python client/client.py activate A
python client/client.py status
```

## Configuration

Edit `resort_config.yaml` to configure:
- Motor settings (ID, baudrate, device)
- Hotel positions
- Safety parameters

## Hardware Setup

1. Connect Dynamixel motor to power supply (12V)
2. Connect USB2Dynamixel or equivalent adapter
3. Connect adapter to Raspberry Pi USB port
4. Motor should appear as `/dev/ttyUSB0`

## Troubleshooting

### No USB Device Found
```bash
ls /dev/ttyUSB*
```
If nothing appears, check:
- USB adapter connection
- Power to motor
- USB cable

### Permission Issues
```bash
sudo usermod -aG dialout $USER
# Then reboot
```

### Motor Not Responding
```bash
python3 test_scripts/test_dxl_ping.py --device /dev/ttyUSB0 --baud 57600 --id 1
```

## Archived Components

GUI components have been moved to `archived_gui/` directory:
- Web interface (`web_gui.py`)
- Templates and static files
- Desktop launchers
- Web startup scripts

These can be restored if needed for future GUI development.

## Development

The system is designed to be minimal and extensible. Core functionality is in `plate_resort.py` with test utilities in `test_scripts/`.

## Support

- Check motor connections and power
- Verify USB permissions with `groups` command
- Test individual components with scripts in `test_scripts/`

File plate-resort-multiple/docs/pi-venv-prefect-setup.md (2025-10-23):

# Raspberry Pi: venv + Prefect setup (interactive convenience)

This document records the steps we used in the repo to prepare a Raspberry Pi to run the Plate-RESORT worker and to interact with Prefect from the Pi.

It focuses on two related goals:
- create and use a Python virtualenv that contains Prefect and the `plate-resort` package
- make it easy to run Prefect CLI commands interactively on the Pi (convenience auto-activation)

These steps assume a clone of the repository at `/home/ac/plate-RESORT` and that the service will use a venv at `/home/ac/plate-RESORT/plate-resort-env`. Adjust paths if your setup differs.

## 1 — System packages (minimal)
Install system packages on a fresh Pi:

```bash
sudo apt update
sudo apt install -y git python3-venv python3-pip build-essential
```

## 2 — Clone the repository

```bash
cd /home/ac
git clone https://github.com/AccelerationConsortium/plate-RESORT.git
cd plate-RESORT
git fetch origin
git checkout copilot/replace-rest-api-with-prefect
```

## 3 — Create the venv and install the package

We recommend creating a dedicated venv for the project. This keeps dependencies isolated and makes it easy for systemd to run the correct interpreter.

```bash
cd /home/ac/plate-RESORT
python3 -m venv plate-resort-env
source plate-resort-env/bin/activate
pip install --upgrade pip
# editable install so console scripts are available
pip install -e .
```

After this, the venv contains Prefect (pinned to `3.4.23` via `pyproject.toml`) and the `plate-resort` entry points.

## 4 — Secrets & environment variables

Store Prefect credentials and other env vars in a single file that both interactive shells and systemd can use. Create `/home/ac/plate-RESORT/secrets.local.env` with:

```bash
cat > /home/ac/plate-RESORT/secrets.local.env <<EOF
PREFECT_API_URL=https://api.prefect.cloud/api/accounts/<ACCOUNT>/workspaces/<WORKSPACE>
PREFECT_API_KEY=<YOUR_API_KEY>
PREFECT_CLI_PROMPT=false
EOF

chown ac:ac /home/ac/plate-RESORT/secrets.local.env
chmod 600 /home/ac/plate-RESORT/secrets.local.env
```

Notes:
- `PREFECT_CLI_PROMPT=false` prevents any interactive CLI prompts (important for non-interactive systemd usage).
- Keep this file untracked (do not add to git); treat it as a local secret store.

## 5 — Convenience: auto-activate the venv in your interactive shells

If you frequently SSH into the Pi and want your interactive shell to have the venv active automatically, add the following to `~/.bashrc` (for user `ac`):

```bash
# Auto-activate plate-resort venv for interactive shells
if [ -n "$PS1" ] && [ -d "/home/ac/plate-RESORT/plate-resort-env" ]; then
  # export vars from secrets.local.env without printing
  if [ -f /home/ac/plate-RESORT/secrets.local.env ]; then
    set -a
    source /home/ac/plate-RESORT/secrets.local.env
    set +a
  fi
  source /home/ac/plate-RESORT/plate-resort-env/bin/activate
fi
```

This makes interactive sessions convenient: `prefect` and project console scripts are immediately available. Note this is strictly for interactive convenience only — systemd will not rely on `~/.bashrc`.

## 6 — Systemd / service note (non-interactive)

For services, do NOT rely on shell activation. Instead, use the venv python directly in the unit file. Example ExecStart:

```ini
ExecStart=/home/ac/plate-RESORT/plate-resort-env/bin/python -m plate_resort.workflows.worker_service
EnvironmentFile=/home/ac/plate-RESORT/secrets.local.env
Environment=PREFECT_CLI_PROMPT=false
```

This is robust and ensures the service uses the same environment as your interactive venv.

## 7 — Using Prefect on the Pi (examples)

Run from an activated shell (convenient):

```bash
source /home/ac/plate-RESORT/plate-resort-env/bin/activate
# optionally source secrets so envs are present
set -a; source /home/ac/plate-RESORT/secrets.local.env; set +a

# list available deployments
prefect deployment ls

# run a deployment by name and watch logs
prefect deployment run my-flow/my-deployment --watch

# run by id
prefect deployment run --id <DEPLOYMENT-ID> --watch
```

Run without activation (explicit venv python — reproducible):

```bash
/home/ac/plate-RESORT/plate-resort-env/bin/python -m prefect deployment run my-flow/my-deployment --watch
```

Run the local package CLI scripts (installed by `pip install -e .`) without activation:

```bash
/home/ac/plate-RESORT/plate-resort-env/bin/plate-resort-worker
# or via python -m
/home/ac/plate-RESORT/plate-resort-env/bin/python -m plate_resort.workflows.worker_service
```

## 8 — Quick health checks

Use `systemctl` and `journalctl` when diagnosing service behavior:

```bash
sudo systemctl status plate-resort.service
sudo journalctl -u plate-resort.service -f
```

## 9 — Reboot behavior

If the systemd unit is enabled, the worker will start automatically on reboot. After reboot, confirm with `systemctl status` and `journalctl`.

## 10 — Troubleshooting

- If `prefect` is not found in an interactive shell, either activate the venv or call the venv python as shown above.
- If the service prompts or aborts, ensure `PREFECT_CLI_PROMPT=false` is set in the env file and that the unit uses the venv python directly.
- If a flow run fails with hardware errors, run the same code manually from an activated venv to get full tracebacks and hardware logs.

---

This document mirrors the steps we used in our working session and can be copied to other Pi targets. If you want, I can add a single `provision_pi.sh` script that automates everything (clone, venv, install, unit copy, enable). Want that next?

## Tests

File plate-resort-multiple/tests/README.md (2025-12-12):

# Test Scripts

Essential testing scripts for the Plate Resort system hardware and motor diagnostics.

## Prerequisites

Install the plate-resort package:
```bash
pip install -e .  # From the root directory
```

## Quick Test Scripts

### Hotel Activation
```bash
python activate_hotel.py B    # Activate hotel B
python activate_hotel.py A    # Activate hotel A
python activate_hotel.py C    # Activate hotel C  
python activate_hotel.py D    # Activate hotel D
```

### Status Check
```bash
python status.py             # Show current position, settings, and hotel positions
```

### Manual Positioning
```bash
python move_to.py 45.5       # Move to 45.5 degrees
python move_to.py 90         # Move to 90 degrees
```

## Available Tests

### Hardware Tests
- **`test_dxl_ping.py`** - Test basic Dynamixel communication
- **`test_motor_health.py`** - Check motor health and diagnostics
- **`test_plate_resort.py`** - Complete system functionality test

### Interactive Tests  
- **`test_dxl_keyboard.py`** - Manual motor control with keyboard

## Usage

Run any test directly:
```bash
python test_scripts/test_dxl_ping.py
python test_scripts/test_motor_health.py
```

For interactive client testing, use the main client tools:
```bash
python interactive_client.py    # Interactive CLI
python demo_client.py          # Automated demo
```

### 🔧 `test_plate_resort.py`
Tests the main PlateResort functionality:
- Motor connection
- Hotel positions and movement
- Configuration loading

```bash
cd test_scripts
python test_plate_resort.py
```

### 🏥 `test_motor_health.py`
Monitors motor health during operations:
- Temperature, current, position tracking
- Health checks before/after movements
- Warning detection

```bash
cd test_scripts
python test_motor_health.py
```

### 🔍 `test_dxl_ping.py`
Low-level Dynamixel motor diagnostics:
- Motor connectivity testing
- Hardware error status checking
- Direct motor communication

```bash
cd test_scripts
python test_dxl_ping.py --device /dev/ttyUSB0 --id 1
```

### ⌨️ `test_dxl_keyboard.py`
Interactive motor control:
- Manual motor positioning
- Real-time position feedback
- Keyboard-based motor control

```bash
cd test_scripts
python test_dxl_keyboard.py
```

## Configuration

Most scripts use the default configuration included in the package. To use a custom configuration, place `resort_config.yaml` in the current directory.

## Troubleshooting

- **Import errors**: Make sure the package is installed (`pip install -e .`)
- **USB permission errors**: On Linux, add user to `dialout` group
- **Motor not found**: Check USB connection and device path
- **Configuration errors**: Verify YAML syntax and motor settings

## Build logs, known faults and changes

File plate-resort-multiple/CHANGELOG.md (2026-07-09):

# Changelog

All notable changes to this project will be documented in this file.

## [2.1.2] - 2026-07-09
### Fixed
- Position and current reads no longer fail when a hardware fault latches mid-move: the servo sets the alert bit on every status packet, which `_read_position_deg`/`_read_current_ma` treated as a failed read. A fault during a move surfaced as `read_fail` with `position None` (and crashed the test report) instead of naming the fault. Reads now only require comm success and record the alert bit.
- `move()` aborts as soon as the alert bit appears, returning `reason="hardware_fault"` with the decoded Hardware Error Status (e.g. "overload"), final position, and peak current — so a mid-move fault reports what tripped and where it stopped.
- `tests/test_closed_loop.py` report is None-safe and prints decoded fault names.

## [2.1.1] - 2026-07-09
### Added
- `connect()` now recovers from a latched Hardware Error Status (e.g. overload shutdown): it decodes the fault bits, reboots the servo, and verifies the flag cleared before applying configuration. Previously the first checked write raised on the alert bit, so `reboot()` — the recovery path — could never be reached; `soft_reset.py` was wedged by the very fault it exists to clear.
- `max_speed` config key (default 17 ≈ 3.9 rpm — full rotation ≈ 15 s): upper bound enforced by `set_speed()` and at connect; `default_speed` lowered to match. Values < 1 are always rejected — Profile Velocity 0 means "no velocity profile" on Dynamixel (an unlimited-speed move), not slow/stopped. Configs without the key fall back to a permissive 100 so existing user configs keep connecting.

### Fixed
- `_read_hardware_error()` returned None exactly when a fault was latched, because the servo sets the alert bit in the error byte of every status packet while faulted — the very condition the read exists to diagnose. It now checks only the comm result.
- `tests/status.py` printed the long-dead `enable_precise_move` flag (it was never read by any control code); it now shows the operating mode and PID gains.

## [2.1.0] - 2026-07-08
### Changed
- Replaced the two-stage (coarse position + host-side PWM pulse) movement strategy with a single closed-loop move executed by the servo's internal controller. Root cause of the chronic undershoot was the firmware's default Position I Gain of 0: a P-only controller parks where its output balances load friction, leaving a load-proportional steady-state error. The PWM pulse stage compounded this by freewheeling (Goal PWM 0) between pulses, letting the loaded carousel back-drive, and by leaving the servo in PWM mode after every move so subsequent Goal Position writes were silently ignored.
- Default operating mode is now Current-based Position Control (5): multi-turn goals with torque capped by `goal_current_ma`. Non-zero `position_i_gain` (default 300) drives steady-state error to zero under load; firmware anti-windup is built in.
- Moves are wrap-aware and shortest-path (no more 350° swings across the 0/360 seam); Present Position is decoded as signed and scaled by 4096 counts/rev.
- All control-critical register writes are now checked (`getTxRxResult`/`getRxPacketError`) instead of silently discarded.

### Added
- `move(angle, tolerance, timeout)` — verified closed-loop move returning `{success, reason, final_angle, final_error, elapsed_s, peak_current_ma, hardware_error}`. Peak current lets you judge torque headroom (XM430-W210 stall ≈ 2.3 A @ 12 V).
- `goto_hotel(hotel, ...)` — verified hotel activation returning the same result dict.
- `show_control_params()` / `tune_control(**updates)` — runtime gain/limit tuning that re-applies the servo configuration immediately.
- Multi-turn housekeeping: the turn counter is reset (Clear Multi-turn) after settling once accumulated rotation exceeds `multi_turn_clear_revs`.
- `tests/test_closed_loop.py` — hardware test (single hotel, `--angle`, `--cycle`) plus `--selftest` angle-math checks that run without hardware.
- New config keys: `operating_mode`, `position_p_gain`, `position_i_gain`, `position_d_gain`, `feedforward_1st_gain`, `feedforward_2nd_gain`, `goal_current_ma`, `current_limit_register_ma` (optional), `settle_polls`, `settle_poll_interval`, `multi_turn_clear_revs`.

### Fixed
- `activate_hotel` is no longer blind: it performs the verified move and returns the real outcome (the REST server path previously always reported success without checking position).
- Model detection now recognizes the deployed motor (XM430-W210, model number 1030).
- `get_motor_health` read Present Input Voltage (addr 144) where it meant Present Current (addr 126); current telemetry was a constant ~323 mA and the overcurrent warning could never fire.
- `set_current_limit_safe` now converts mA to register units (2.69 mA/LSB), clamps to the model ceiling, performs the required torque-off EEPROM write, and reports the actual result. Previously the raw-mA write was out of range on the W210 and silently rejected.
- Negative/out-of-range goals from `rotation_direction: -1` are gone: hotel angles normalize into [0, 360) and multi-turn goals are computed from the present position.
- Misleading `default_speed` comment ("slow but enough torque"): Profile Velocity only shapes the trajectory and does not add torque; slow profiles actually aggravate stiction stalls under P-only control.

### Removed
- `_two_stage_move`, `_set_mode`, and all pulse-stage config keys (`pulse_pwm_start`, `pwm_step`, `pwm_max`, `pulse_duration`, `pulse_rest`, `pulse_max`, `motion_threshold`, `stall_pulses`, `enable_backoff`, `max_step_factor`, `pwm_backoff_step`, `switch_error`, `stage1_timeout`, `poll_interval`, `enable_precise_move`, `precise_log`) and the dead `goal_torque`/`torque_limit`/`moving_threshold` keys. `activate_hotel_precise`/`move_to_angle_precise` remain as deprecated wrappers that ignore pulse-era overrides and return the same result-dict shape (`pulses` is always 0).

## [2.0.50] - 2025-10-31
### Added
- `diagnostics/xm430_simple_debug.py`: minimal two-mode (position mode 3, PWM pulse mode 16) script for direct tuning without advanced stall/plateau logic. Provides adjustable profile velocity/accel and current limit in position mode; short escalating PWM pulses (pulse, rest, check) until within tolerance.

### Notes
- Intended for quick manual torque/position experimentation. Use legacy `xm430_debug.py` for comprehensive near-target stall recovery features.

## [2.0.51] - 2025-10-31
### Added
- Utility flags in `xm430_simple_debug.py`: `--reboot` (soft device reboot) and `--motor-data` (single-line telemetry: position, raw current, voltage, temperature).
## [2.0.52] - 2025-10-31
### Changed
- Refactored `xm430_simple_debug.py` to remove CLI flags; now uses in-file `CONFIG` dict for port, baud, ID, action, and tuning values (simpler manual debugging workflow).

### Notes
- Set `CONFIG["ACTION"]` to `position`, `pwm_pulse`, `reboot`, or `data` then run: `python diagnostics/xm430_simple_debug.py`.
- Previous flag-based invocation retained in history; script now focused on rapid edit-run cycles.

## [2.0.53] - 2025-10-31
### Added

### Notes

## [2.0.54] - 2025-10-31
### Added
Added adaptive backoff near target: when a pulse produces a delta > `TOLERANCE * MAX_STEP_FACTOR` and error is within `SWITCH_ERROR`, PWM is reduced by `PWM_BACKOFF_STEP` (bounded by `PULSE_PWM_START`). This prevents large jumps >1.5x tolerance during final approach. Refactored long lines for lint compliance.

## [2.0.55] - 2025-10-31
### Added
- Adaptive backoff + stall detection in two-stage pulse phase (hard-coded factors for initial trial: 1.5 movement factor, 80 PWM backoff, stall after 6 low-motion pulses).
### Changed
- Stage 2 now stops early on stall instead of only hitting max pulses.

## [2.0.56] - 2025-10-31
### Added
- Integrated two-stage precise movement strategy into `PlateResort`: new methods `activate_hotel_precise` and `move_to_angle_precise` perform coarse position move then PWM pulse refinement with adaptive escalation, backoff and stall detection.
- New config keys in `config/defaults.yaml` under `resort:` for tuning: `enable_precise_move`, `switch_error`, `stage1_timeout`, `poll_interval`, `pulse_pwm_start`, `pwm_step`, `pwm_max`, `pulse_duration`, `pulse_rest`, `pulse_max`, `motion_threshold`, `stall_pulses`, `enable_backoff`, `max_step_factor`, `pwm_backoff_step`, `precise_log`.
### Notes
- Legacy `activate_hotel` retained (blind immediate command). Use `activate_hotel_precise` when confirmation within tolerance and controlled near-target approach are required.

## [2.0.57] - 2025-10-31
### Added
- Runtime tuning helpers `show_precise_params()` and `tune_precise(**updates)` to inspect and adjust precise movement parameters without editing YAML.
### Changed
- More conservative fallback defaults in `_precise_cfg` (lower start PWM, slower escalation, slightly larger switch error). Helps prevent aggressive overshoot when user override file lacks new keys.
### Notes
- `tune_precise` modifications are in-memory only; update `~/plate-resort-config/defaults.yaml` to persist across sessions.
## [2.0.58] - 2025-10-31
## [2.0.59] - 2025-10-31
## [2.0.60] - 2025-10-31
### Added
- `reboot` Prefect flow: performs soft reboot of Dynamixel, optional reapplication of mode, current limit, goal current, profile velocity & acceleration, and returns a health snapshot.
- Orchestrator helper `reboot(wait=0.8, reapply=True)` for remote triggering.
### Changed
- Core: added `PlateResort.reboot(wait=0.8, reapply=True)` method with safety torque disable before reboot and controlled reapply sequence.
### Notes
- Use reboot to clear transient hardware error bits or communication glitches. For persistent thermal/overload conditions, a full power cycle is still recommended.
### Changed
- Prefect `activate_hotel` flow now performs precise two-stage activation by default (coarse position + PWM pulse refinement). Added `precise` boolean parameter to fall back to legacy blind activation when needed.
- Flow returns the precise result dict (success, reason, pulses, final_angle, final_error) when `precise=True` for remote observability.
- Orchestrator client function `activate_hotel` updated to accept `precise` flag and arbitrary precise parameter overrides (forwarded to flow).
### Added
- Ability to override precise tuning parameters per remote call (e.g., `pulse_pwm_start`, `switch_error`) without editing configuration files.
### Notes
- External clients can now inspect fine-grained outcome data directly from the flow run result state.
### Fixed
- Corrected misuse of control table address 32 (Velocity Limit) for torque/current limiting; now writes current limit to address 38 (`ADDR_CURRENT_LIMIT`).
- Ensured profile velocity (addr 112) and optional profile acceleration (addr 108) are re-applied after every operating mode switch in precise movement helper `_set_mode`.
### Changed
- Refactored comment for goal current register to clarify applicability only in Current / Current-based Position modes (0 or 5); harmless when written in Position mode (3).
- Wrapped long lines in `core.py` to satisfy lint width constraints.
### Notes
- Slower Stage 1 positioning can now be reliably tuned via `default_speed` (profile velocity) and `profile_acceleration` since writes persist after mode transitions.
- For further near-target refinement adjust `pulse_pwm_start`, `pwm_step`, and `pwm_backoff_step` in `defaults.yaml` or via `tune_precise()`.

### Notes
- Reboot performs protocol reboot then waits ~0.8s before exit; torque disabled during cleanup.
- Voltage reported as decoded 0.1V units; current is raw value (no mA conversion applied).

## [2.0.61] - 2025-10-31
### Fixed
- Prefect `activate_hotel` flow parameter schema error (`'overrides' is a required property`) caused by variadic `**overrides`. Replaced with explicit optional `overrides: dict | None` parameter so deployments no longer require an overrides object.
### Changed
- Orchestrator helper `activate_hotel` now accepts `overrides: dict | None` and forwards only when provided.
### Notes
- To pass overrides remotely use: `--param overrides='{"pulse_pwm_start": 140, "pwm_step": 20}'` (CLI JSON string) or programmatically `activate_hotel("A", overrides={"pulse_pwm_start":140})`.

## [2.0.62] - 2025-10-31
### Added
- Prefect flow structured logging via `get_run_logger()` for: `activate_hotel`, `get_motor_health`, `move_to_angle`, `set_speed`, `get_current_position`, `reboot`, and `emergency_stop`.
- Orchestrator `watch(flow_run, ...)` helper streams live Prefect logs and final state to stdout.
### Changed
- Activation, health and reboot flows now emit concise telemetry lines (angle, error, temperature, hardware error) visible in Prefect UI and through `watch`.
### Notes
- Use `watch(oz.activate_hotel("A"))` in a Python session for real-time progress without opening the UI.

## [2.0.49] - 2025-10-30
### Added
- Diagnostics: Finish pulsed torque mode (`--finish-pulse-mode` + related flags) providing discrete short current pulses in finish Current Mode (0) as an alternative to continuous creep. Adaptive escalation of pulse current when motion below threshold; optional restore to holding mode.

### Changed
- Diagnostics: Early stage advancement decoupled from stall logic; `--stage-advance-error` now advances immediately when residual error is between tolerance and threshold (no need to trigger a stall).
- Diagnostics: Simplified stall heuristic (no `--stall-error-threshold`); stall now means no improvement for `--stall-window` while still outside tolerance.
- Diagnostics: Automatic skip of remaining stages when already within tolerance of the final target after completing (or partially completing) an earlier stage (prints `[SKIP]`).

### Removed
- Diagnostics: Deprecated `--stall-error-threshold` argument (behavior superseded by simplified stall rule).

### Added Flags
- `--finish-pulse-mode`, `--finish-pulse-current-start`, `--finish-pulse-current-step`, `--finish-pulse-current-max`, `--finish-pulse-duration`, `--finish-pulse-rest`, `--finish-pulse-motion-threshold`, `--finish-pulse-max-pulses`, `--finish-pulse-abort-error-increase`, `--finish-pulse-restore-mode`.

### Notes
- `--finish-pulse-mode` and `--finish-current-creep` are mutually exclusive; choose one strategy for gentle final seating.
- Use pulses when you want deterministic short torque applications and clear observation windows between them; use creep for continuous low-to-high torque ramp.
- Existing plateau interventions (dither/pulse/surge/nudge/PWM/burst) unchanged.

## [2.0.25] - 2025-10-29

## [2.0.26] - 2025-10-30
## [2.0.27] - 2025-10-30
## [2.0.28] - 2025-10-30
## [2.0.47] - 2025-10-30
### Added
## [2.0.48] - 2025-10-30
### Added
- Diagnostics: Adaptive finish current creep feature (`--finish-current-creep` + related flags) enabling controlled final torque-only approach in Current Mode (0). Starts at low goal current and escalates in steps until motion meets threshold or target within tolerance; optional automatic restore to holding mode (default Mode 5).

### Flags
- `--finish-current-creep`: enable feature when using `--finish-mode 0`.
- `--finish-current-start`, `--finish-current-step`, `--finish-current-interval`, `--finish-current-max` for escalation control.
- `--finish-current-motion-threshold`: minimal angle delta per interval to consider motion; below this escalates current.
- `--finish-current-max-time`: safety cap on creep duration.
- `--finish-current-restore-mode`: restore to positional/holding mode after success (default 5; -1 disables restore).
- `--finish-current-abort-error-increase`: abort if error grows too much indicating runaway.

### Notes
- Use with two-stage move (Mode 3 coarse -> Mode 0 finish + creep) when very gentle final insertion torque is required without overshoot.
- If creep stalls at max current, consider reducing friction or allowing a higher `--finish-current-max` within safe thermal limits.

- Diagnostics: Optional reboot on start (`--reboot-on-start`, wait configurable via `--reboot-wait`) to clear certain transient/latched states before baseline reads.
- Post-reboot immediate hardware error status verification prints cleared (0x00) or persisting bits.

### Guidance
- Reboot helps for transient communication glitches, stale moving flags, or cleared overload bits that have already self-recovered. It does NOT replace a full power cycle for thermal shutdown or persistent overload due to real mechanical jam.
- Prefer power cycle if: temperature remains high (bit 0x02 repeatedly) or overload (0x10) reappears immediately after reboot.

### Notes
- Combine with `--preflight-hw-error-checks` to distinguish freshly latched errors from those that reboot clears.

### Fixed
- Diagnostics: corrected torque enable write (removed invalid unpack of return values in `xm430_debug.py`).

### Notes
- Re-run diagnostics to ensure torque enabling proceeds without ValueError.

## [2.0.29] - 2025-10-30

### Fixed
- Diagnostics: guarded against `None` present current (TypeError on `abs(None)`), corrected per-line current display when value is zero, and replaced summary max current with max absolute current.

### Added
- Peak torque phase reporting (timestamp, angle, error, current) in diagnostics summary.

### Notes
- Run: `python diagnostics/xm430_debug.py --port COM3 --baud 57600 --id 1 --operating-mode 5 --current-limit 1023 --goal-current 300 --profile-velocity 30 --profile-accel 10 --target-angle 190 --tolerance 2.0` and review Peak torque phase line.

### Fixed
- Corrected diagnostic script control table addresses for XM430 (voltage=144, temperature=146, moving=122).
- Added `--tolerance` parameter, early success exit, absolute current display.

### Notes
- Run with: `python diagnostics/xm430_debug.py --port COM3 --baud 57600 --id 1 --operating-mode 5 --current-limit 1023 --goal-current 300 --profile-velocity 30 --profile-accel 10 --target-angle 180 --tolerance 2.0`

### Added
- `diagnostics/xm430_debug.py` direct XM430-210-T motor diagnostic script for manual serial testing (operating mode, current limit, profile velocity/accel, stall heuristic, current/voltage/temp telemetry).

### Notes
- Use to evaluate heavy-load stall behavior outside Prefect. Run: `python diagnostics/xm430_debug.py --port COM3 --baud 57600 --id 1 --operating-mode 5 --goal-current 300 --current-limit 1023 --profile-velocity 50 --profile-accel 10 --target-angle 180`.

### Changed
- Restored legacy blind hotel activation: `activate_hotel` now immediately returns success after issuing goal position without polling / position verification. This matches earlier behavior where activation succeeded even if position feedback intermittently failed.

### Notes
- Remote flows relying on `activate_hotel` will no longer block or fail due to position read errors. Use a future diagnostic flow or `get_motor_health` to inspect position when available.

## [2.0.24] - 2025-10-27
## [2.0.33] - 2025-10-30
## [2.0.34] - 2025-10-30
## [2.0.35] - 2025-10-30
## [2.0.36] - 2025-10-30

### Added
- Diagnostics: High-torque surge escalation (`--surge-enabled`) performing temporary current mode ramp (`--surge-start`, `--surge-max`, `--surge-step`, `--surge-hold`, `--surge-cool`) with safety gates (`--surge-temp-ceil`, `--surge-voltage-floor`) and optional plateau progress reset (`--surge-reset-progress`).

### Changed
- Plateau escalation order: dither -> pulse -> surge -> nudge.

### Notes
- Use surge after verifying temperature remains safely below thermal limits; surge attempts to reach near current limit briefly to overcome static friction.

### Added
- Diagnostics: `--keep-finish-mode` flag plus automatic restoration of original operating mode & torque state after finish-mode run (safety cleanup).
- Diagnostics: Nudge execution telemetry (`nudge_attempted`, `nudge_failed`) with warning-only failure path (no hard abort).

### Changed
- Diagnostics: Plateau nudge errors now emit `[NUDGE-WARN]` and allow script to continue to summary instead of leaving hardware in ambiguous state.

### Notes
- Use `--keep-finish-mode` if you want to stay in the finish operating mode for subsequent manual moves; otherwise mode auto-restores.

### Added
- Diagnostics: Finish-stage operating mode switch (`--finish-mode`) allowing transition (e.g., mode 5 -> 3) near final target once tolerance window reached.
- Diagnostics: Plateau detection (`--plateau-window`, `--plateau-delta`) with proactive in-loop nudge pattern (`--nudge-enabled`, `--nudge-pattern`, `--nudge-wait`) to overcome static friction before overall timeout.

### Changed
- Diagnostics: Final-stage logic now tracks progress separately from earlier stages; nudge executes immediately on plateau instead of only at timeout.

### Notes
- Example usage:
	`python diagnostics/xm430_debug.py --port COM3 --baud 57600 --id 1 \
	 --operating-mode 5 --current-limit 1023 --goal-current 750 \
	 --profile-velocity 70 --profile-accel 20 --pre-angle 95 \
	 --final-profile-velocity 25 --final-profile-accel 10 --target-angle 90 \
	 --ramp-final-current --ramp-step 25 --ramp-interval 1.0 --ramp-max 900 \
	 --ramp-min-error 3.0 --finish-mode 3 --finish-window 8 \
	 --nudge-enabled --nudge-pattern +1,-2,+1 --tolerance 2.0`

### Added
- Diagnostics: Adaptive final-stage current ramp (`--ramp-final-current`) with safety thresholds (temp, voltage) and adjustable parameters (`--ramp-step`, `--ramp-interval`, `--ramp-max`, `--ramp-min-error`, `--ramp-temp-ceil`, `--ramp-voltage-floor`).

### Notes
- Use together with `--pre-angle` and final profile overrides to approach target smoothly, then ramp torque only if small residual error persists.
- Example:
	`python diagnostics/xm430_debug.py --port COM3 --baud 57600 --id 1 \
		 --operating-mode 5 --current-limit 1023 --goal-current 750 \
		 --profile-velocity 70 --profile-accel 20 --pre-angle 95 \
		 --final-profile-velocity 25 --final-profile-accel 10 --target-angle 90 \
		 --ramp-final-current --ramp-step 25 --ramp-interval 1.0 --ramp-max 900 \
		 --ramp-min-error 3.0 --tolerance 2.0`
## [2.0.37] - 2025-10-30

### Added
- Diagnostics: `--plateau-all-stages` allows plateau detection & interventions (dither/pulse/surge/nudge) before final stage.
- Diagnostics: `--ramp-all-stages` permits adaptive current ramp during any stage (previously final stage only).
- Diagnostics: `--stage-advance-error` enables early promotion to next stage during a stall when residual error falls below a specified threshold but is still above tolerance.

### Changed
- Stall heuristic now optionally advances to next stage (if configured) to overcome load-induced stall rather than re-issuing the same intermediate goal indefinitely.
- Plateau intervention block generalized (no longer hard-wired to final stage when `--plateau-all-stages` is supplied).

### Notes
- Example heavy-load run leveraging new flags:
	`python diagnostics/xm430_debug.py --port COM3 --baud 57600 --id 1 \
		--operating-mode 5 --current-limit 1023 --goal-current 800 \
		--profile-velocity 70 --profile-accel 20 --pre-angle 95 \
		--final-profile-velocity 35 --final-profile-accel 12 --target-angle 90 \
		--ramp-final-current --ramp-all-stages --ramp-step 30 --ramp-interval 0.9 --ramp-max 1000 \
		--ramp-min-error 12.0 --plateau-all-stages --plateau-window 2.0 --plateau-delta 0.12 \
		--dither-enabled --pulse-enabled --surge-enabled --surge-start 900 --surge-max 1020 --surge-step 30 \
		--stage-advance-error 15.0 --nudge-enabled --tolerance 2.0`

	Use `--stage-advance-error` cautiously: set it lower than the expected residual error after coarse positioning but high enough to avoid premature advancement when large error remains.
	## [2.0.38] - 2025-10-30

	### Added
	- Diagnostics: `--plateau-cooldown` to suppress repeated plateau intervention spam; waits configurable seconds before re-running full dither/pulse/surge/nudge chain.
	- Diagnostics: Plateau skip reason aggregation in summary (`cooldown_active`, `nudge_disabled_or_already_done`).

	### Changed
	- Ramp abort messages for temperature/voltage now printed once per condition (de-duplicated logging).
	- Plateau detection logic refactored to compute condition + cooldown separately for clarity.

	### Notes
	- If plateau still persists just above tolerance, consider reducing `--tolerance` slightly or increasing `--nudge-amplitude` (future flag) — for now adjust `--nudge-pattern` magnitudes cautiously.
	## [2.0.39] - 2025-10-30

	### Added
	- Diagnostics: PWM proportional nudge feature (`--pwm-nudge-enabled`) switches temporarily to PWM Mode (16) and applies a PWM value proportional to residual error (`--pwm-nudge-kp`, limited by `--pwm-nudge-max`) to break static friction.
	- Safety & control flags: `--pwm-nudge-duration`, `--pwm-nudge-cooldown`, `--pwm-nudge-temp-ceil`, `--pwm-nudge-voltage-floor` for gating and spacing interventions.

	### Changed
	- Plateau intervention sequence optionally ends with PWM proportional nudge if enabled, after surge/nudge steps.
	- Summary now reports PWM nudge execution status and applied PWM value.

	### Notes
	- Suggested initial tuning: `--pwm-nudge-kp 30.0 --pwm-nudge-duration 0.25 --pwm-nudge-cooldown 5.0`.
	- Increase `--pwm-nudge-kp` gradually; watch temperature and hardware error bits (overload) for risk.
	## [2.0.40] - 2025-10-30

	- Diagnostics: Micro nudge feature (`--micro-nudge-enabled`, `--micro-nudge-kp`, `--micro-nudge-max-step`, `--micro-nudge-disable-below-error`, `--micro-nudge-wait`) providing gentle proportional position corrections when near-target plateau persists.

	## [2.0.43] - 2025-10-30
	### Changed
	- Diagnostics: Burst defaults tuned to prior effective parameters (`--burst-start-current 372`, `--burst-max-current 560`, `--burst-hold-max-time 3.0`, unchanged `--burst-current-step 30`, `--burst-motion-threshold 0.25`).
	- Diagnostics: Unlimited burst cycles supported when `--burst-max-cycles <= 0`; script will continue executing short cycles until success, safety abort, or ineffective improvement.

	### Added
	- Per-cycle improvement evaluation remains; unlimited mode respects `--burst-improvement-threshold` for early exit when adequate progress achieved.

	### Notes
	- Use `--burst-max-cycles 0` to allow sustained near-target torque probing without manually setting a high cycle count.
	- Diagnostics: Plateau minimum error gate (`--plateau-min-error`) suppresses heavy escalation (dither/pulse/surge/nudge/PWM) for very small residual errors; micro nudge still allowed.
	Refined burst nudge into short, gated multi-cycle behavior:
	- Added near-target gating flag `--burst-trigger-max-error` (default 15°) so burst only engages after stall close to target.
	- Introduced cycle controls: `--burst-max-cycles`, `--burst-cycle-hold`, `--burst-cycle-gap`, `--burst-ramp-max-steps` for short controlled ramps.
	- Added improvement threshold `--burst-improvement-threshold` to stop early when effective progress achieved.
	- Ensures restoration of operating mode between cycles and safety checks each cycle.
	- Provides per-cycle improvement logging.

	### Changed
	- Plateau block now evaluates `heavy_allowed` based on residual error vs `--plateau-min-error` before executing heavy interventions.
	- Micro nudge execution recorded via skip reason list (`micro_nudge_executed`).

	### Notes
	- Suggested initial micro nudge tuning: `--micro-nudge-kp 0.35 --micro-nudge-max-step 0.8 --plateau-min-error 3.0`.
	- If chatter occurs near target, raise `--micro-nudge-disable-below-error` or increase `--plateau-min-error`.
	## [2.0.41] - 2025-10-30

	### Added
	- Diagnostics: Burst nudge feature (`--burst-nudge-enabled`) implementing a ramp-to-motion-and-hold strategy. Temporarily switches to Current Mode (0), ramps current in steps (`--burst-start-current`, `--burst-current-step`, `--burst-max-current`, `--burst-step-interval`) until a minimal motion threshold (`--burst-motion-threshold`) is detected, then holds current while monitoring residual error (`--burst-hold-max-time`, `--burst-hold-interval`). Safety gating via temperature and voltage (`--burst-temp-ceil`, `--burst-voltage-floor`) and a freeze guard (`--burst-freeze-error`) to avoid unnecessary torque when already near target.

	### Changed
	- Plateau intervention sequence now optionally ends with Burst nudge after PWM nudge when enabled and residual error remains above freeze threshold.
	- Summary reports burst outcome (`Burst nudge executed successfully`, incomplete or failed reason) and safety abort reasons.

	### Notes
	- Suggested initial tuning for gentle correction: `--burst-start-current 120 --burst-current-step 30 --burst-max-current 950 --burst-motion-threshold 0.25 --burst-hold-max-time 4.0`.
	- If ramp reaches max without motion, outcome shows `no_motion`; consider increasing `--burst-current-step` or verifying mechanical load.
	- Use with micro nudge + plateau gating: `--micro-nudge-enabled --plateau-min-error 3.0 --burst-freeze-error 2.5` to reserve burst for moderately stuck cases.
## [2.0.32] - 2025-10-30
## [2.0.44] - 2025-10-30
### Added
- Diagnostics: Communication fault detection. Counts consecutive NaN position reads and performs a one-time soft torque cycle reset after 5 polls; aborts with guidance if still NaN after additional 5.

### Changed
- Summary and inline fault messages clarify when a hard power cycle is recommended.
### Notes
- Use `--show-errors` to surface hardware error status bits; persistent NaN without error bits typically indicates cabling / power / ID mismatch.
- Diagnostics: Two-stage move support via `--pre-angle` then final target.
- Diagnostics: Optional slower final approach overrides with `--final-profile-velocity` and `--final-profile-accel`.
	`python diagnostics/xm430_debug.py --port COM3 --baud 57600 --id 1 \
		 --operating-mode 5 --current-limit 1023 --goal-current 800 \
		 --profile-velocity 70 --profile-accel 20 --pre-angle 95 \

### Added
  - `--burst-expand-increment` raw increment added to the active burst max.
  - `--burst-expand-max` ceiling for escalation (defaults to current limit or 1023).
### Changed
- Burst loop now tracks `active` max current and escalates cautiously after ineffective cycles, respecting thermal/voltage safety offsets (`temp >= burst_temp_ceil - 2`, `voltage < burst_voltage_floor + 0.2` blocks expansion).
- Summary reports final escalated max and number of expansion steps.

### Notes
- Use: `--burst-nudge-enabled --burst-expand-enabled --burst-max-cycles 0` for persistent near-target torque probing with automatic escalation.
- Initial tuning suggestion: keep `--burst-expand-increment` moderate (30–50) to observe thermal response; raise only if repeated cycles remain ineffective.
- If oscillations regress (negative improvement), expansions will trigger when below threshold; consider slightly increasing `--burst-improvement-threshold` to force faster escalation.
## [2.0.31] - 2025-10-30

### Added
- Diagnostics: Hardware Error Status (addr 70) read each poll; optional decoded output with `--show-errors`.
- Diagnostics: Per-line display of `hwErr=0x..` when present; summary lists distinct hardware error codes observed.

### Notes
- Use with `--show-errors` to identify overload (bit 0x10), voltage (0x01), or thermal (0x02) conditions contributing to near-target stall.

## [2.0.30] - 2025-10-30

### Added
- Diagnostics: `--ping` flag to verify motor ID / model number before further operations.
- Diagnostics: `--verbose` flag to print register read failures (result/error codes) for debugging missing telemetry.
- Diagnostics: Early abort if all initial position reads are NaN/None (likely wiring, power, or incorrect ID).

### Notes
- Use `python diagnostics/xm430_debug.py --port COM3 --baud 57600 --id 1 --ping` to confirm connectivity. If ping fails, inspect cabling and power. If ping succeeds but telemetry is None, run with `--verbose` to see failing addresses.

### Added
- README note detailing redeployment options: branch ref vs commit hash (Option B) and clarifying that commit pinning resolved previous missing entrypoint path issues.

### Notes
- Documentation-only change. Prefer `PLATE_RESORT_GIT_COMMIT=$(git rev-parse HEAD)` before `plate-resort-deploy` for reproducible deployments.

## [2.0.23] - 2025-10-27

### Fixed
- `deploy.py` now uses `GitRepository(reference=PLATE_RESORT_GIT_REF)` when no commit SHA is provided instead of cloning a default path blindly, preventing missing entrypoint errors on non-main branches.

### Notes
- Set `PLATE_RESORT_GIT_COMMIT` to pin a specific commit (takes precedence over ref).

## [2.0.22] - 2025-10-27

### Changed
- Major README overhaul: removed duplicate/inconsistent sections; consolidated Quick Start, client setup (interactive vs example script), configuration overrides, troubleshooting table.

### Added
- Explicit documentation of `client-requirements.txt` and `plate_resort/client/env.sh` usage.

### Notes
- No functional code changes; documentation only.

## [2.0.21] - 2025-10-27

### Added
- Restored minimal interactive CLI at `plate_resort/client/interactive.py` supporting local and remote Prefect submissions (commands: connect, activate <hotel>, position, stop, disconnect).

### Notes
- Console script `plate-resort-interactive` now functions again for both modes; remote requires PREFECT_API_URL and PREFECT_API_KEY.

## [2.0.20] - 2025-10-27

### Changed
- Flows (`activate_hotel`, `go_home`, `move_to_angle`, `set_speed`, `get_motor_health`, `get_current_position`, `emergency_stop`) no longer auto-disconnect or release torque after completion. Connection remains active to keep motor locked unless the explicit `disconnect` flow is run.

### Removed
- Deprecated local hardware test scripts and example chaining script from `tests/`.
- Pi-specific venv setup doc (`docs/pi-venv-prefect-setup.md`) superseded by simpler deployment approach.
- Legacy installer scripts (`install.sh`, `bootstrap_pi.sh`) replaced by direct venv + plate-resort-deploy instructions in README.

### Added
- Relocated client example to `plate_resort/client/example_prefect_client.py`.
- Added `plate_resort/client/env.sh` for quick environment variable export.

### Notes
- Ensures motor holds position continuously between operations. Use `disconnect` flow to intentionally release torque and close port.

## [2.0.19] - 2025-10-27

### Changed
- Consolidated client examples into `tests/example_prefect_client.py` demonstrating sequential hotel activation (A→D) with completion waits after each activation.
- Removed older verbose scripts (`test_orchestrator_connect_activate.py`, `example_chain_hotels.py`).

### Notes
- Waiting is optional; core orchestrator functions remain non-blocking unless `orchestrator.wait()` is invoked.

## [2.0.18] - 2025-10-27

### Added
- `orchestrator.wait(flow_run)` helper for optional blocking until a flow run reaches a final state (polling Prefect Cloud).
- Example chaining script `tests/example_chain_hotels.py` demonstrating sequential hotel activation (A→D) in blocking and non-blocking modes.

### Notes
- Non-blocking behavior remains default; blocking is opt-in for safety-critical sequences.
- Minimal example script for connect + activate remains unchanged.

## [2.0.17] - 2025-10-27

### Changed
- Cleaned and refocused `README.md` on Prefect Cloud orchestration: clarified remote workflow submission uses Prefect deployments and the Pi process worker; removed legacy REST/keygen notes section.
- Added explicit references to setup scripts (`install.sh`, `bootstrap_pi.sh`) and systemd unit usage for persistent worker.

### Notes
- Environment override `PLATE_RESORT_POOL` documented; systemd unit and installer continue to auto-deploy when Prefect env vars are present.
## [2.0.5] - 2025-10-16
## [2.0.6] - 2025-10-16
## [2.0.11] - 2025-10-21

## [2.0.12] - 2025-10-21

## [2.0.13] - 2025-10-21

## [2.0.14] - 2025-10-21

## [2.0.15] - 2025-10-21

### Fixed
- Corrected `GitRepository` initialization (uses `url=` not `repo_url=`) and added
	local path presence warning to help diagnose layout mismatches.

### Notes
- Set `PLATE_RESORT_GIT_COMMIT` to a commit containing `plate-resort-multiple/plate_resort/workflows/flows.py` before redeploy.

### Added
- Commit pinning support in `deploy.py` via `PLATE_RESORT_GIT_COMMIT` (uses GitRepository storage).

### Changed
- Improved warnings when a commit SHA is not supplied (falls back to default branch).

### Notes
- For reproducible deployments: `export PLATE_RESORT_GIT_COMMIT=$(git rev-parse HEAD)` then run `plate-resort-deploy`.

### Fixed
- Corrected Prefect Cloud deployment entrypoint path to include top-level folder
	`plate-resort-multiple/` so remote cloning resolves `flows.py`.

### Notes
- Redeploy with `plate-resort-deploy` to register fixed entrypoints.

### Added
- Remote Git repository source in `deploy.py` using `flow.from_source` to satisfy Prefect Cloud requirement for image or storage without building a container image.

### Changed
- Deployment script now prints git ref (env `PLATE_RESORT_GIT_REF`, default `main`).

### Notes
- Use `export PLATE_RESORT_GIT_REF=<branch-or-tag>` before `plate-resort-deploy` to pin a version.
- No container image needed; worker clones repo directly.

### Fixed
- Removed unsupported `entrypoint` argument from `Flow.deploy` calls (Prefect 3.4.23 API does not accept it).

### Notes
- Run `plate-resort-deploy` again to register flows without error.

## [2.0.16] - 2025-10-23

### Notes
- Operational status: the persistent worker and key deployments (connect, activate-hotel) are exercising correctly in Prefect Cloud — activation and connection flows submit and run as expected.
- Known issue: `get-position` has intermittently crashed in a small number of runs (observed as CRASHED). This is documented and intentionally left unfixed for now; core functionality (connect, activate-hotel) prioritized.

## [2.0.10] - 2025-10-21

### Fixed
- `deploy.py` now handles Prefect Flow objects correctly (uses `flow.fn` instead of passing Flow object to `inspect.getsourcefile`), preventing TypeError during deployment.

### Notes
- Re-run `plate-resort-deploy` after upgrading to register deployments successfully.

## [2.0.9] - 2025-10-21

### Changed
- `PlateResort.connect` now accepts optional overrides: `device`, `baudrate`, `motor_id` for flow parameter pass-through.

### Removed
- Console script entries for deleted artifacts (`plate-resort-demo`, `plate-resort-update`).

### Notes
- Function-based Prefect flows can now supply connection parameters safely without signature mismatch crashes.

## [2.0.8] - 2025-10-21

### Removed
- Legacy artifacts: `plate_resort/utils/keygen.py`, `plate_resort/utils/update.py`, `plate_resort/client/demo.py`, temporary `test_counter` Prefect flow method, duplicate `is_connected`.
- Legacy config search path entry for `resort_config.yaml`.

### Changed
- `.gitignore` now ignores `archived/`, `archived_gui/`, and `verify_prefect.py` (archives retained locally).
- Clarified hotel angle computation comment in `defaults.yaml`.
- Consolidated single `is_connected` method.

### Notes
- Archives preserved for reference but excluded from change tracking; consider moving to separate branch in future.

## [2.0.7] - 2025-10-16

### Fixed
- Deployment failures due to Prefect attempting to read a non-existent script path (`/home/pi/plate_resort/core.py`). Added explicit module entrypoints in `deploy.py` so flows are resolved from `plate_resort.workflows.flows:<function>` rather than inferred file paths.

### Added
- Deployment output now prints each flow's entrypoint string along with s  Stored in directory: /tmp/pip-ephem-wheel-cache-8mgnby2f/wheels/0b/aa/c0/11eecf10bed573525c496e7254c0e4a38ec0a80e991cc2e583
Successfully built plate-resort
Installing collected packages: pyserial, websockets, uvloop, urllib3, typing-extensions, sniffio, pyyaml, python-dotenv, idna, httptools, h11, dynamixel-sdk, click, charset_normalizer, certifi, annotated-types, uvicorn, typing-inspection, requests, pydantic-core, anyio, watchfiles, starlette, pydantic, fastapi, plate-resort
Successfully installed annotated-types-0.7.0 anyio-4.11.0 certifi-2025.10.5 charset_normalizer-3.4.4 click-8.3.0 dynamixel-sdk-3.8.4 fastapi-0.119.1 h11-0.16.0 httptools-0.7.1 idna-3.11 plate-resort-2.0.0 pydantic-2.12.3 pydantic-core-2.41.4 pyserial-3.5 python-dotenv-1.1.1 pyyaml-6.0.3 requests-2.32.5 sniffio-1.3.1 starlette-0.48.0 typing-extensions-4.15.0 typing-inspection-0.4.2 urllib3-2.5.0 uvicorn-0.38.0 uvloop-0.22.1 watchfiles-1.1.1 websockets-15.0.1
-bash: plate-resort-deploy: command not found
-bash: prefect: command not found
-bash: prefect: command not foundource file.

### Notes
- If stale `deploy.py` persists, fully uninstall (`pip uninstall -y plate-resort`), remove any `plate_resort*` directories in the venv `site-packages`, then reinstall with `--force-refresh`.

### Added
- `install.sh` flags: `--force-refresh` (delete venv + no pip cache), `--ref <git-ref>` (override branch/tag/commit for install).

### Changed
- Installer now prints the git ref used for clarity.
- Force refresh bypasses wheel and HTTP caches to ensure latest remote commit is fetched.

### Notes
- Use `--force-refresh` when suspecting stale artifacts or cached wheels.
- `--ref` enables pinning to a release tag or commit SHA for reproducible setups.

### Added
- Debug instrumentation in `plate_resort.workflows.deploy` to print source file path for each flow function during deployment.

### Fixed
- Began addressing Prefect deployment import path mismatch (`FileNotFoundError: /home/pi/plate_resort/core.py`). The package installs under `site-packages/plate_resort/` but Prefect attempted to load a filesystem path as if it were a loose script. Debug output will help confirm correct `site-packages` path on the Raspberry Pi.

### Notes
- If Prefect still resolves `/home/pi/plate_resort/core.py`, ensure the virtual environment has the package installed (not just a partial copy) and that `plate_resort` is not shadowed by a directory named `plate_resort` in `$HOME`. Remove/rename any stray `$HOME/plate_resort/` directory to avoid import shadowing.

## [2.0.4] - 2025-10-16

### Removed
- Orphaned `plate-resort-keygen` console script entry from `pyproject.toml` (legacy REST/key generation utility fully retired).

### Changed
- Updated `README.md` to reflect Prefect-only architecture and environment variable based authentication (removed residual keygen / REST references).
 - Simplified `install.sh`; now auto-deploys flows and starts worker when Prefect env vars are present.
 - Bumped package version to 2.0.4.

### Notes
- Key generation is no longer part of the workflow; use Prefect Cloud API credentials via environment variables.

## [2.0.3] - 2025-10-16

### Added
- `bootstrap_pi.sh` script for end-to-end fresh Raspberry Pi setup (clone, venv, deploy Prefect flows, start worker).
- `verify_prefect.py` diagnostic script to confirm Prefect Cloud connectivity, work pool presence, deployments, and recent flow runs.

### Changed
- Pinned Prefect dependency to `prefect==3.4.23` for stable flow deployment behavior.

### Notes
- Future Prefect upgrades should edit pin deliberately; run `verify_prefect.py` after any upgrade.

## [2.0.1] - 2025-10-15

### Fixed
- Resolved Prefect Cloud flow crash (SignatureMismatchError) by removing extraneous parameters from remote `connect` deployment submission.
- Updated `orchestrator.connect()` to call `run_deployment(name="connect/connect")` without a parameter dict (method flow expects only `self`).

### Notes
- Other flows (activate-hotel, move-to-angle, etc.) retain parameters matching their method signatures.
- No breaking API changes; remote client now successfully submits `connect` without crashing.

## [2.1.0] - 2025-01-XX

## [2.0.2] - 2025-10-15

### Changed
- Removed `@flow` decorators from `PlateResort` class methods to eliminate signature mismatches.
- Deployments now source only function-based flows in `plate_resort/workflows/flows.py`.
- `deploy.py` refactored to use explicit function list (`FUNCTION_FLOWS`).
- `orchestrator.connect` restored to accept device/baud/motor parameters for the function flow.

### Fixed
- Resolved repeated CRASHED flow runs caused by method-based deployments passing unexpected parameters.

### Notes
- Class still usable locally; Prefect orchestration isolated to stateless function flows.

### Added
- Prefect v3 integration for workflow orchestration
- `prefect_flows/device.py` - Prefect flows for device control
- `prefect_flows/orchestrator.py` - Remote flow execution functions
- `prefect_flows/README.md` - Setup and usage documentation

### Changed
- Added Prefect>=3.0.0 to dependencies
- REST API remains available but Prefect is now the recommended approach

### Notes
- Prefect provides better observability, retry logic, and async execution
- No breaking changes - REST API still functional for backward compatibility

## [2.0.0] - 2025-10-07

### 🎉 Major Release: Pip Package + Automatic Setup

**BREAKING CHANGES:**
- Complete transformation to pip-installable package
- Simplified installation and usage
- Archived all legacy installers

### 🆕 New Package Structure
- **pip installable**: `pip install git+https://github.com/...`
- **Command line tools**: `plate-resort-server`, `plate-resort-client`, `plate-resort-setup`
- **Professional package**: `plate_resort` Python package
- **Automatic setup**: System dependencies, USB permissions, API keys

### ✨ New Features
- One-line installation with automatic setup
- Command-line tools for server and client
- Automatic USB permissions and system configuration
- Professional Python package structure
- pip-based dependency management

### 🗂️ Archived Components
- Legacy bash installers (install.sh, update.sh)
- Standalone server/ and client/ directories
- Manual setup scripts and GUI components
- All deprecated files moved to archived/

### 🔧 Installation Methods
- **Recommended**: `curl ... | bash` (pip + auto-setup)
- **Manual**: `pip install ...` + `plate-resort-setup`
- **Development**: `pip install -e .` for local development

### 📦 Package Contents
- `plate_resort.core` - Motor control logic
- `plate_resort.server` - FastAPI REST API
- `plate_resort.client` - Client library and CLI
- `plate_resort.setup` - System setup automation
- `plate_resort.keygen` - API key management

### 🎯 Usage Simplification
- **Server**: `plate-resort-server` (instead of bash scripts)
- **Client**: `plate-resort-client --host IP` (consistent CLI)
- **Setup**: `plate-resort-setup` (automated system config)
- **Keys**: `plate-resort-keygen` (secure key generation)

### 🚀 Deployment Ready
- Works on any Python 3.8+ system
- Automatic Raspberry Pi detection and setup
- Professional dependency management
- Clean separation of server/client concerns

## [1.4.0] - 2025-10-07 (Archived)

### Removed
- Docker references and configuration
- Raspberry Pi specific deployment scripts

### Changed
- Simplified deployment approach
- Direct Python execution without containers

### Added
- CHANGELOG.md for tracking version history
- .gitignore file to prevent cache/temp files in repo

### Removed
- Redundant GUI implementations (gui.py, touchscreen_app.py, app.py)
- Redundant launcher scripts and duplicate implementations
- Duplicate test file from root directory (dxl_keyboard_test.py)
- Python cache directories (__pycache__)

### Changed
- Updated README.md to reflect cleaned project structure
- Simplified file organization following copilot-instructions

## [1.2.0] - 2025-09-10

### Added
- Disconnect and reconnect functionality to web API endpoints
- Connection control buttons in web interface (Disconnect/Reconnect)
- `is_connected()` method to PlateResort class for connection status checking
- Enhanced error handling for connection states
- Active hotel display logic improvements

### Fixed
- Emergency stop recovery - system no longer freezes after emergency stop
- Active hotel display now correctly shows current hotel (A, B, C, D, Home, Moving)
- Connection state management and status reporting

## [1.1.0] - 2025-09-10

### Added
- Professional web-based GUI with Bootstrap styling
- Fullscreen support optimized for 7" touchscreen (800x480)
- Live motor health monitoring with real-time updates
- Debug panel with live data logging
- Simplified deployment with automated dependency management
- Automated startup scripts and desktop integration
- Clean repo structure with organized test files

### Changed
- Migrated from Tkinter to Flask web-based GUI
- Moved all test files to `test_scripts/` directory
- Simplified deployment to single web GUI service
- Updated documentation for new architecture

### Removed
- Legacy GUI implementations (gui.py, touchscreen_app.py)
- Duplicate launcher scripts
- Emoji usage for professional lab environment

## [1.0.0] - 2025-09-10

### Added
- Initial PlateResort class with YAML configuration
- Dynamixel motor control with health monitoring
- Hotel position management (A, B, C, D)
- Emergency stop functionality
- Basic motor health reporting
- Raspberry Pi deployment scripts
- Raspberry Pi deployment scripts

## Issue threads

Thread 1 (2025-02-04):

Project log

kelvinchow23, 2025-02-04:
Initial build of a single plate hotel with 10 slots. There's standoffs at 25mm increments along the post to accommodate well plates (or other labware) of different heights.

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

kelvinchow23, 2025-02-07:
Link to training lab post on turntables: https://github.com/AccelerationConsortium/ac-training-lab/issues/17#issuecomment-2622099256

kelvinchow23, 2025-02-25:
the well plate trays were printed with the bambul print profile 0.16mm optimal. Stuart also suggested that these trays be embossed with a deck number from 1-10. I'm not sure how to iteratively generate these labels, so i manually embossed them in bambu studio.

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

kelvinchow23, 2025-02-27:
i built a second one yesterday and realized maybe alignment of the trays may need to be cleaned up. maybe tighten the screws almost all the way, lie the plate hotel horizontally, then screw it in?

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

kelvinchow23, 2025-03-11:
here's a different iteration of the plate hotel using a similar concept of vertical din rails with standoffs spaced 25mm apart.  This is to store other labware like glass vials (on top) and dosing rack.

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

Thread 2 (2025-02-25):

Plate carousel project log

kelvinchow23, 2025-02-25:

kelvinchow23, 2025-02-25:
i discussed this [here](https://github.com/AccelerationConsortium/ac-training-lab/issues/17),a bit. I think a servo motor might be enough even if we scale up to a heavier plate carousel (i dont know how heavy they'll get, say 20 pounds?).  I'm going to try to build a turntable, load it with 20 pounds or close, and see how it responds.  Here was my first open loop servo motor that Ilya gave me, had a range up to 270 degrees.

https://github.com/user-attachments/assets/432fcef9-b8ab-446b-8ec1-48fdd7928318

kelvinchow23, 2025-02-25:
I swapped out the motor to one with a feedback signal. (https://ca.robotshop.com/products/17kg-digital-servo-w-feedback-fb5118m?variant=42487950934167).  This motor has slightly less torque (17kg.cm), more range (0-300), and the feedback. the video below is running closed loop with PID feedback.

https://github.com/user-attachments/assets/c5c2759c-077e-437b-bc85-ef320c247909

kelvinchow23, 2025-02-25:
its sometimes helpful to track states for error proofing. for instance in one column, theres 8 slots full and 3 slots empty. This is what is stored on the controller. If a user for some reason decided to take off a well plate, this is going to throw off the workflow. Thinking about this, is there some switch or sensor to tell if there is a well plate present? How useful will this functionality be?  My intention was to use a pi zero 2w (or some board with a camera connector) in case it is useful to use a camera to detect the state of the plates. However, i realized afterwards that the pi zero does not have an adc, so the servo motor w/ feedback doesn't directly work with the pi zero without an external adc module. right now, i'm going to abandon the pi zero and use the pico to test if i can repeatably, reliably position the plate carousel in 6 set positions and figure out later if states are necessary.
At the minimum, there's going to need the functionality of a user manually loading all the slots with empty well plates at the beginning of the workflow and then storing the state of the carousel as we go.

kelvinchow23, 2025-02-25:
this is my plate carousel so far, starting with the mecahnical parts:
I made the base a wider, about 8inches. . Around the perimeter there's 4 [small rollers](https://www.igus.ca/product/xiros_axial_B180_POM). it says each one can withstand a 7-8lbs load. I bought a different variation thats larger that can withstand a higher load if necessary. i ilke plastic rollers because theyre maintenance free.

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

In the middle, theres a roller bearing. The servo is mounted underneath to that disc, and this [shaft ](https://www.gobilda.com/1910-series-servo-hub-shaft-25-tooth-spline-10mm-shaft-diameter-33mm-length/)sits ontop of the disc. This is the same manufacturer as the servocity turntable, i bought out the stock of these shafts on robotshop.
This shaft will be mounted to a rotating disc where the plate hotel/carousel sits on.

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

https://github.com/user-attachments/assets/302b86bd-b1de-498c-99c3-0df3fc7303fb

kelvinchow23, 2025-02-25:
i wired up the pico and server to a switch and power connector, then assembled a partially built carousel onto the rotating disc.

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

here's about a 20lb load on the turntable, it's nice that filaments are sold in quantities of 1kg.

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

after putting 20lbs on it, i really don't think the carousel will every load that much weight, maybe half that weight.

kelvinchow23, 2025-02-25:
that rotating disc is probably flexing and is unsupported at the centre where the servo is. Would help if it was an aluminium disc. at the very least, some standoffs installed in the base would be nice

kelvinchow23, 2025-05-21:
i let it sit for a  couple months loaded with weight. there's definitely bowing issues. the rotating disc is not in contact with all 4 ball bearing supports.

kelvinchow23, 2025-06-02:
making a new iteration. i'm going to add a base plate and have 8 aluminum standoffs, 4 in the middle where the servo is mounted and 4 on the perimeters near the outer roller supports. In the image below, the top plate is translucent to view the inside mounting to reduce deflection over time. The new design is going to be 1 metre tall (increased from 2ft), so a little worried how much this can reduce swaying. might want to think about changing this from a central mounting point to multiple mounting points around a ring, kind of like a slewing bearing or turntable bearing. that would increase the cost, but might be necessary if the resort is going to be so tall.

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

kelvinchow23, 2025-06-02:
thinking about workflows, it seems like in this application, there will need to be a regrip station somewhere (to change from landscape to portrait gripping). is there a way this can be built in around this module?

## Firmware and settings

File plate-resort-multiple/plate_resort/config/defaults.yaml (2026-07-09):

# PlateResort Configuration
resort:
  # Hardware settings
  device: "/dev/ttyUSB0"
  baudrate: 57600
  motor_id: 1
  
  # Physical layout
  hotels: ["A", "B", "C", "D"]
  rooms_per_hotel: 20
  
  # Positioning
  offset_angle: 19  # Base offset angle in degrees
  rotation_direction: 1  # 1 for clockwise, -1 for counter-clockwise
  
  # Hotel positions computed dynamically:
  # angle_i = offset_angle + i * (360 / len(hotels)) * rotation_direction
  
  # Movement settings
  default_speed: 17  # Profile Velocity register (0.229 rpm/unit; 17 ≈ 3.9 rpm ≈ 23 °/s — full rotation ≈ 15 s). Shapes the trajectory only — does NOT limit torque.
  max_speed: 17      # Upper bound accepted by set_speed()/config (17 keeps a full rotation at ≈ 15 s or slower). Values < 1 are always rejected: Profile Velocity 0 means NO velocity profile (unlimited-speed move), not slow.
  position_tolerance: 0.5  # Position accuracy in degrees
  movement_timeout: 20  # Max wait time in seconds
  profile_acceleration: 10  # Profile Acceleration register (214.577 rev/min²/unit; 10 ≈ 215 °/s²). 0 = infinite (step); gentle ramp reduces stick-slip on a heavy carousel.

  # Closed-loop control (servo-internal PID does the work; host only verifies)
  operating_mode: 5        # 5 = current-based position control (multi-turn, torque capped by goal_current_ma); 3 = plain single-turn position mode
  position_p_gain: 800     # Firmware default 800
  position_i_gain: 300     # Firmware default is 0 — non-zero I removes the load-induced steady-state error (undershoot). Increase until droop is gone; if it oscillates/overshoots, raise position_d_gain or lower I. Firmware anti-windup is built in.
  position_d_gain: 0       # Add damping if the integral term causes overshoot (try 100-500)
  feedforward_1st_gain: 0  # Velocity feedforward: cuts tracking lag during the move (does not affect final accuracy)
  feedforward_2nd_gain: 0  # Acceleration feedforward
  goal_current_ma: 2000    # Torque cap in mode 5 (mA). Must exceed the load's breakaway torque or moves will stall short by design. XM430-W210 stall ≈ 2300 mA @ 12 V; register ceiling ≈ 3209 mA.
  # current_limit_register_ma: 3200  # Optional: write the Current Limit EEPROM register (mA). Unset = keep factory limit.

  # Settle verification (host-side)
  settle_polls: 3           # Consecutive in-tolerance polls to declare success
  settle_poll_interval: 0.05  # Seconds between polls
  multi_turn_clear_revs: 2.0  # Reset the multi-turn counter after settling beyond this many accumulated revolutions

  # Health monitoring
  temperature_limit: 70  # Temperature warning threshold (°C)
  current_limit: 2000  # Current warning threshold (mA)
  voltage_min: 10.0  # Minimum voltage warning (V)
  voltage_max: 14.0  # Maximum voltage warning (V)

# Prefect Configuration
prefect:
  # Workflow settings
  server_host: "0.0.0.0"
  server_port: 4200
  
  # Work pool settings
  # Default value kept for backward compatibility. You can override at runtime
  # by setting the PLATE_RESORT_POOL environment variable.
  work_pool_name: "plate-resort-pool"
  worker_name: "plate-resort-worker"
  
  # Flow settings
  default_retries: 3
  retry_delay_seconds: 5

# REST API Server Configuration
server:
  # Network settings
  host: "0.0.0.0"  # Bind to all interfaces
  port: 8000
  
  # Security
  api_key: "changeme"  # Generate secure key with: plate-resort-keygen --generate
  # API key can be overridden with PLATE_API_KEY environment variable
  # For deployment: Set PLATE_API_KEY environment variable or run plate-resort-keygen
  
  # API settings
  reload: false  # Enable auto-reload during development
  docs_enabled: true  # Enable /docs endpoint

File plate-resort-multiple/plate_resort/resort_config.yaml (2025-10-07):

# PlateResort Configuration
resort:
  # Hardware settings
  device: "/dev/ttyUSB0"
  baudrate: 57600
  motor_id: 1
  
  # Physical layout
  hotels: ["A", "B", "C", "D"]
  rooms_per_hotel: 20
  
  # Positioning
  offset_angle: 19  # Base offset angle in degrees
  rotation_direction: 1  # 1 for clockwise, -1 for counter-clockwise
  
  # Hotel positions (calculated from offset_angle and hotels)
  # Hotels A,B,C,D are at 90° intervals starting from offset_angle
  
  # Movement settings
  default_speed: 50  # Profile velocity (50 = ~5% speed)
  position_tolerance: 0.5  # Position accuracy in degrees
  movement_timeout: 20  # Max wait time in seconds
  
  # Torque settings
  goal_torque: 1023  # Max torque output (0-1023, 1023 = 100%)
  torque_limit: 1023  # Torque limit for safety (0-1023)
  
  # Health monitoring
  temperature_limit: 70  # Temperature warning threshold (°C)
  current_limit: 2000  # Current warning threshold (mA)
  voltage_min: 10.0  # Minimum voltage warning (V)
  voltage_max: 14.0  # Maximum voltage warning (V)
  
  # Advanced motor settings
  profile_acceleration: 0  # 0 = default acceleration
  moving_threshold: 10  # Movement detection threshold

# Server Configuration
server:
  # Network settings
  host: "0.0.0.0"  # Bind to all interfaces
  port: 8000
  ip: "100.83.140.57"  # External IP for client connections
  
  # Security
  api_key: "changeme"  # Default key - generate secure key with: python generate_api_key.py --generate --update-config
  # API key can be overridden with PLATE_API_KEY environment variable
  
  # API settings
  reload: true  # Enable auto-reload during development
  docs_enabled: true  # Enable /docs endpoint

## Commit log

2025-02-21 intial commit
    project initial commit, build instructions need pictures and carousel is work in progress
    [4xB1 well_plate_trays.3mf, B1 well_plate_tray RevA.step, B1 well_plate_tray RevA.stl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]
2025-06-01 renamed folders
    [4xB1 well_plate_trays.3mf, B1 well_plate_tray RevA.step, B1 well_plate_tray RevA.stl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]
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2025-06-10 Update servo_controller.py
    reverted back to cc4aba8
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2025-06-18 moving to dynamixel servo
    [plate-resort-BOM-RevA.xlsx]
2025-09-10 Add Docker support for Dynamixel controller
    - Added Dockerfile with Python 3.9 environment
    - Added docker-compose.yml for easy container management
    - Includes USB device mapping for /dev/ttyUSB0
    - Enables isolated pip package installation on Pi
2025-09-10 Clean up repository: remove non-Dynamixel files and organize structure
    - Removed: button_manager, display_manager, snake_game, servo_*, adc_manager, test_pid_servo, test_pwm_calibration
    - Removed: resort-controller.py, resort-firmware.py (old servo system)
    - Moved: plate-resort-BOM-RevA.xlsx to mechanical/ directory
    - Simplified: requirements.txt to only include dynamixel-sdk
    - Focused: Repository now contains only Dynamixel XM430 control code and Docker setup
    [plate-resort-BOM-RevA.xlsx]
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2025-09-10 Add YAML config system and motor health monitoring
    - YAML configuration for all settings (torque, health limits, positioning)
    - Motor health monitoring (temperature, current, voltage, errors)
    - Max torque output configuration
    - Health warning system with configurable thresholds
    - Health monitoring test script
    - Updated requirements.txt with pyyaml
    [plate_resort.py, resort_config.yaml, test_motor_health.py]
2025-09-10 Add modern GUI and deployment system
    - Add modern fullscreen Tkinter GUI with tabbed interface (gui.py)
    - Add comprehensive launcher script for all modes (launch.sh)
    - Add desktop integration and autostart setup scripts
    - Features: live debug data, health monitoring, visual indicators
    - Ready for 7 inch touchscreen deployment on Raspberry Pi
2025-09-10 Fix GUI initialization and bash script syntax
    - Fix PlateResortGUI constructor call in touchscreen_app.py
    - Fix bash script docstring syntax in launch.sh
2025-09-10 Fix position config and add debug logging
    - Add missing positions section to resort_config.yaml
    - Add terminal debug logging to GUI position updates
    - Handle missing position config gracefully
    - Improve docker-launch.sh logging message
    [resort_config.yaml]
2025-09-10 Fix motor movement - add missing methods and correct GUI calls
    CRITICAL BUG FIXES:
    - Add missing go_home() and emergency_stop() methods to PlateResort class
    - Fix GUI to call activate_hotel() instead of non-existent go_to_hotel()
    - Add comprehensive debug logging to track movement issues
    - Move all motor operations to background threads to prevent GUI freezing
    - Add success/failure detection for movements
    The motor wasn't moving because GUI was calling methods that didn't exist!
    [plate_resort.py, resort_config.yaml]
2025-09-10 Add disconnect/reconnect functionality and fix active hotel display
    - Added disconnect and reconnect endpoints to web API
    - Added connection control buttons to web interface
    - Improved active hotel display logic in status endpoint
    - Added is_connected method to PlateResort class
    - Enhanced error handling for connection states
    [plate_resort.py, web_gui.py]
2025-09-10 Clean up repo structure following copilot-instructions
    - Added CHANGELOG.md for version tracking
    - Added .gitignore to prevent cache files
    - Removed redundant GUI files (gui.py, touchscreen_app.py, app.py)
    - Removed redundant launcher scripts
    - Removed duplicate test files from root
    - Updated README.md with current structure
    - Simplified project to single web GUI implementation
    Repository now follows lean development practices with minimal implementations.
2025-10-07 feat: Convert to server-only deployment with one-line install
    - Remove Docker deployment (Dockerfile, docker-compose.yml)
    - Archive GUI components to archived_gui/ directory
    - Create one-line installer script (install.sh)
    - Streamline requirements.txt to core dependencies only
    - Update documentation for server-focused usage
    - Add example_usage.py for basic API demonstration
    - Create QUICK_SETUP.md for simplified deployment guide
    - Remove all GUI references from README and documentation
    Breaking Changes:
    - Web GUI no longer available by default (archived)
    - Docker deployment removed
    - Focus shifted to direct Python API usage
    Migration:
    - Use install.sh for fresh Pi installations
    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
    [example_usage.py, web_gui.py]
2025-10-07 fix: Navigate to correct subdirectory in install script
    - Change to plate-resort-multiple subdirectory after clone
    - Fix paths in documentation and output messages
    - Ensure requirements.txt is found during installation
2025-10-07 feat: Add FastAPI server-client architecture
    - Add server/ directory with FastAPI REST API
    - Add client/ directory with Python client library and CLI
    - Create threadsafe wrapper around PlateResort class
    - Add API authentication with configurable key
    - Update requirements.txt with FastAPI dependencies
    - Add server startup script and documentation
    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
2025-10-07 Clean up repository: archive outdated files and consolidate documentation
    - Archive GUI-related files (PI_DEPLOYMENT.md, setup scripts, GUI tests)
    - Archive redundant documentation (QUICK_SETUP.md)
    - Archive old setup scripts (replaced by install.sh)
    - Consolidate README.md with server-client architecture focus
    - Update CHANGELOG.md for v2.0.0 server-client release
    - Improve install.sh for existing Pi installations
    - Add update.sh for quick updates
    Repository now focused on core server-client architecture with clean structure
    [example_usage.py, test_gui_local.py, test_pi_gui.py]
2025-10-07 Add comprehensive API key management and configuration system
    New Features:
    - generate_api_key.py: Secure API key generator with multiple options
    - Server config from YAML: IP, port, API key all configurable
    - Environment variable override support for API keys
    - Security warnings for default/weak keys
    Configuration Improvements:
    - resort_config.yaml: Added server section with IP (100.83.140.57)
    - run_server.sh: Reads config dynamically, shows correct URLs
    - FastAPI server: Loads settings from config file
    - Enhanced API key validation with better error messages
    Security Enhancements:
    - .env file support for API keys (git-ignored)
    - Three-tier key loading: env var > config > default
    - Aut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
    [generate_api_key.py, resort_config.yaml]
2025-10-07 MAJOR: Transform to professional pip package with automatic setup
    Complete Package Transformation:
    - Pip installable: pip install git+https://github.com/...
    - Command line tools: plate-resort-server, plate-resort-client, plate-resort-setup
    - Professional Python package structure with pyproject.toml
    - One-line installation with automatic system configuration
    New Command Line Tools:
    - plate-resort-server: Start FastAPI server (replaces bash scripts)
    - plate-resort-client: Remote control with proper argument parsing
    - plate-resort-setup: Automatic USB permissions, dependencies, config
    - plate-resort-keygen: Secure API key generation and management
    Archived Legacy Components:
    - Old bash ins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
    [core.py, generate_api_key.py, plate_resort.py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]
2025-10-07 Fix installer for externally-managed Python environments
    - Use virtual environment instead of --user install
    - Handle modern Python/Debian restrictions (PEP 668)
    - Install python3-venv and python3-full dependencies
    - Add virtual environment bin to PATH automatically
    Fixes installation on modern Raspberry Pi OS and other systems
    with externally-managed Python environments.
2025-10-07 Simplify setup: Remove unnecessary USB permissions checks
    - USB permissions work by default on modern Raspberry Pi OS
    - Remove complex reboot/permission logic from setup.py
    - Server now starts immediately after installation
    - Cleaner user experience without confusing permission prompts
2025-10-07 Fix setup script: Create secrets.ini in package directory
    The server looks for secrets.ini relative to the package, but setup
    was creating it in the current working directory. This caused the
    server to fall back to the default API key.
    Now creates secrets.ini in the correct location where server can find it.
2025-10-07 Add position and move_to_angle functionality
    - Added get_current_position() and move_to_angle() methods to core
    - Added /position and /move_to_angle endpoints to server
    - Added position and move commands to CLI client
    - Fixed interactive client authentication issues
    - Updated demo and interactive clients with new functionality
    - All clients now support direct angle movement and position queries
    [core.py, test_motor_health.py]
2025-10-07 Add plate-resort-update command for easy server updates
    - Added plate-resort-update script for one-command server updates
    - Updates package from latest GitHub automatically
    - Handles systemd service restart automatically
    - Provides clear feedback and next steps
2025-10-07 Fix missing move_to_angle and get_current_position methods in server wrapper
    - Added move_to_angle method to PlateResortWrapper class
    - Added get_current_position method to PlateResortWrapper class
    - Fixed interactive client to use correct method name move_to_angle
    - Server 500 errors should now be resolved
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2025-10-07 Remove device.py and fix deployment to avoid hardware initialization
2025-10-15 Complete restructure: eliminate REST API, implement Prefect-only workflow orchestration
    - Removed all REST API components (FastAPI, uvicorn dependencies)
    - Restructured into clean package layout:
    - plate_resort/client/: Client interaction tools with PlateResortClient class
    - plate_resort/config/: Configuration management
    - plate_resort/workflows/: Prefect orchestration
    - plate_resort/utils/: Utility functions
    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
2025-10-15 Improve installation and config management
    - Fix config path resolution to prioritize user home directory
    - Auto-activate venv in new terminals and after reboot
    - Automatically create secrets.ini from template
    - Better installation feedback and instructions
    - Config files now properly copied to ~/plate-resort-config/
    [core.py]
2025-10-15 Fix flow crashes: remove persistent worker instance, make flows handle connections
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2025-10-16 feat: migrate to stateless Prefect flows, remove REST/keygen, add auto-deploy installer (v2.0.4)
2025-10-16 chore: 2.0.9 deploy inspection fix + client/core fleshing
    [check_workspace.py, core.py]
2025-10-21 fix(deploy): handle Flow objects via flow.fn; bump to 2.0.10
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2025-10-23 docs/secrets: add env-style placeholders and bash examples; make work pool configurable via PLATE_RESORT_POOL; update docs/scripts to reference env override
2025-10-27 docs: README overhaul, restore interactive CLI; feat: persistent connection flows; chore: cleanup obsolete scripts; version 2.0.22
2025-10-27 fix(deploy): honor PLATE_RESORT_GIT_REF via GitRepository.reference; docs: changelog 2.0.23; bump version
2025-10-27 docs: add commit pin deployment note (Option B); bump version to 2.0.24
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2025-10-31 chore(core): correct current limit addr + reapply velocity on mode switch (v2.0.58)
    [core.py]
2025-10-31 feat(reboot): add reboot flow, orchestrator helper, and core reboot method (v2.0.60)
    [core.py]
2025-10-31 fix(flow): make activate_hotel overrides optional (dict) to satisfy Prefect schema; bump to v2.0.61
2025-12-12 Restructure codebase with dual interface architecture
    - Create clean separation between Prefect and REST API interfaces
    - Move workflows to plate_resort/interfaces/prefect/
    - Move REST API server to plate_resort/interfaces/rest_api/
    - Add motor auto-detection (XM430/XL430) with current control support
    - Update console scripts with clear naming (prefect vs rest prefixes)
    - Consolidate key generation to REST-specific keygen_rest.py
    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
2025-12-12 Update documentation with correct REST API client commands
    - Add REST client usage examples to DEPLOYMENT.md showing correct commands
    - Clarify available commands: connect, disconnect, status, position, activate
    - Remove any references to unavailable commands like 'home'
    - Ensure deployment docs match actual CLI implementation
    [pyvenv.cfg]
2025-12-12 Add test scripts and update motor speed configuration
    - Add activate_hotel.py test script for direct hotel activation
    - Add status.py test script for system status checking
    - Add move_to.py test script for manual positioning
    - Add test_two_stage.py to verify precise movement works directly
    - Update tests/README.md with usage examples
    - Set default_speed to 10 for safe, controlled movement
2025-12-12 Remove debug output and finalize two-stage REST API integration
    - Remove DEBUG print from load_api_key function
    - Ensure clean production-ready code
    - REST API now fully uses activate_hotel_precise() for two-stage movement
2026-07-08 feat(control): closed-loop moves via current-based position mode + integral gain
    Replace the two-stage (coarse position + host-side PWM pulse) strategy,
    which undershot under load, with a single verified closed-loop move:
    - Root cause: firmware default Position I Gain = 0 leaves a P-only
    controller that parks with a load-proportional steady-state error.
    The PWM pulse stage freewheeled between pulses (load back-drives),
    counted backslide as progress, and left the servo in PWM mode where
    subsequent Goal Position writes were silently ignored.
    - New default: operating mode 5 (current-based position control) with
    position_i_gain=300, torque capped by goal_current_ma; the servo's
    inte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
    [core.py, defaults.yaml, test_closed_loop.py]
2026-07-09 style: normalize formatting across client, interfaces, and test scripts
    Black-style formatting pass: wrap long signatures/calls, normalize
    string quotes, strip trailing whitespace, add missing final newlines.
    One real (harmless) fix: a comment in prefect/deploy.py moved to the
    loop-body indentation it actually describes. No behavior changes.
    [activate_hotel.py, move_to.py, status.py]
2026-07-09 test: add soft_reset script for motor reboot recovery
    Connects, reboots the servo (reapplying mode/gain config), then
    verifies position reads and motor health. For recovering the motor
    on the Pi after a fault or stuck state.
    [soft_reset.py]
2026-07-09 feat(api): implement REST API for Plate Resort control with motor management endpoints
2026-07-09 fix(control): self-heal latched hardware faults on connect + speed cap
    - connect() now reads Hardware Error Status before configuring: a
    latched fault (e.g. overload shutdown) is decoded, the servo is
    rebooted, and the flag verified clear. Previously the alert bit made
    the first checked write raise, so reboot() was unreachable and
    soft_reset.py was wedged by the very fault it exists to clear.
    - _read_hardware_error() returned None exactly when a fault was
    latched (alert bit rides the error byte of every status packet);
    now only the comm result is checked.
    - New max_speed config key enforced by set_speed() and at connect;
    default 17 units (~3.9 rpm) keeps a full rotation at ~15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
    [core.py, defaults.yaml, status.py]
2026-07-09 fix(control): report mid-move hardware faults instead of read_fail
    A fault latching mid-move (e.g. overload) sets the alert bit on every
    status packet; _read_position_deg/_read_current_ma treated that as a
    failed read, so move() returned read_fail with position None and the
    test report crashed formatting it. The actual fault was never named.
    - Reads now require only comm success; the alert bit is recorded in
    self._alert instead of invalidating the value.
    - move() aborts on alert with reason='hardware_fault', the decoded
    Hardware Error Status, final position, and peak current.
    - test_closed_loop report is None-safe and prints decoded fault names.
    Verified with mocked servo: fault mid-mo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
    [core.py, test_closed_loop.py]
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2026-11-10 Restructure as open-source hardware project; retire Dynamixel software
    - Dedicate repo to the rotating Plate Resort; plate hotel moves to
    hardware/plate-hotel (CAD, print files, BOM, assembly guide, configurations)
    - Remove Dynamixel/Prefect control code, archived GUI/server, committed venv,
    and obsolete docs; keep the Tic stepper bench tool and its tests
    - Add hardware/plate-resort (BOM, electronics/wiring), CSV BOMs,
    CERN-OHL-P-2.0 + MIT licenses, CONTRIBUTING, CI, new README
